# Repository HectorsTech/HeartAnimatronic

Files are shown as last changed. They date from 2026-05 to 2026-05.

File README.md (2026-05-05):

# Realistic Silicone Animatronic Heart

Welcome to the repository for the Realistic Silicone Animatronic Heart project! This project details the construction of a highly realistic, beating animatronic heart.

Compared to simpler designs, this version features a more complex mechanism with three independently moving servos. Controlled by an Arduino Micro and a potentiometer, the heart uses step functions to create a natural-looking motion—gradually filling and then quickly contracting in sequence. The speed of the heartbeat is fully adjustable via the potentiometer.

This is an advanced project that involves intricate mechanical assembly and silicone casting.

## ⚠️ Important Considerations

*   **Complexity:** This project involves tricky assembly, soldering in tight spaces, and intermediate-to-advanced 3D printing and casting techniques.
*   **Hardware Variants:** The code provided is specific to the type of servos used. Please read the assembly instructions carefully to ensure you use the correct Arduino sketch.

## 🛠️ Supplies & Bill of Materials

### Mechanism Components

*   **Microcontroller:** Arduino Micro
*   **Servo Driver:** PCA9685 16-channel servo driver board (or equivalent)
*   **Servos (x3):** DS-843MG servos are *highly recommended* for their strength, which is necessary to stretch the silicone skin. (MG90s servos are supported, but less ideal).
*   **Control:** 10K Potentiometer
*   **Power Input:** 5.5mm DC panel input jack
*   **Power Supply:** 5V DC power supply (must be capable of handling the current draw of 3 high-torque servos)
*   **Hardware:** Various metric screws (M1 to M3)
*   **Wiring:** Jumper cables, slightly thicker wire for the power lines

### Casting Materials

*   **Skin:** 500g Platsil Gel 00 (or equivalent ultra-soft silicone)
*   **Mold:** 2kg Tinsil 7025 (or equivalent mold-making silicone)
*   **Release Agent:** Ease Release 205 (or equivalent)
*   **Coloring:** Silicone pigment in dark red
*   **Mold Box:** A suitable container (can be constructed using hot glue and styrene or similar materials)

### Other Tools & Materials

*   3D Printer and filament (PLA/PETG)
*   Airbrush and acrylic paints (for detailing)
*   Pin vice hand drill
*   Soldering Iron & solder
*   Electrical tape / Heat shrink tubing
*   Fake blood (for final presentation)

## 🖨️ Step 1: 3D Printing

There are no strict material requirements for the prints, only that the structural components be reasonably high-resolution and high-strength.

*   **Layer Height:** ~0.2mm is recommended for most structural parts. The outer shell parts can be printed at a lower resolution.
*   **Supports:** The only parts that typically require supports are the outer shell components.
*   **Base Assembly:** The main base is split into two parts for easier printing. They should be glued together and aligned using two M2 x 10mm screws.

*(Refer to the `.stl` files in the repository for all printable components).*

## ⚙️ Step 2: Assembly Guide

The assembly is compact and can be fiddly. It is highly recommended to reference the project video and images throughout this process.

### 1. Servo Installation

Start by inserting the three servos into the base.
*   **Bottom Pair:** Feed the wires through the slots in the base component (you may need to temporarily remove the plastic connector housing on the end of the wire). Secure the servos with M2 x 10mm screws. If using DS-843MG servos, use the small plastic adaptors to fit the M2 screws into the M3 mounting holes.
*   **Top Servo:** This is a tighter fit. You will need to carefully remove the base plate of the servo (where the wire protrudes) to maneuver it into place. Once seated, screw the base plate back on. The design allows for one screw to secure this top servo, but the friction fit should hold it securely.

### 2. Construct the Arm Linkages

1.  Take a standard servo horn and cut it down so only two holes remain.
2.  Attach two "long link" components to the second hole (furthest from the center) of the horn and screw them in.
3.  Take an opposing pair of "arm" components and screw the "long links" to their flat sides.
4.  **Crucial:** Leave these joints loose enough to move freely without binding.
5.  Create two of these sub-assemblies and attach them to the base using an M3 x 10mm screw for each arm.

### 3. Construct the Top Servo Linkage

1.  Use a two-sided servo horn, cutting it down to leave only two holes per side.
2.  Attach a "short link" on the outermost holes, screwing upwards from the bottom using two M2 x 4mm screws. Leave these joints loose enough to pivot.
3.  Use two more M2 x 4mm screws inserted in the opposite direction through the short links to connect to the "rocker" component later.
4.  Attach the "rocker" component to the top of the base using an M3 x 20mm screw.

### 4. Prepare the Servo Driver Board (PCA9685)

Due to space constraints, you cannot use the standard screw terminal block on the PCA9685.
1.  Solder a positive and negative wire (roughly 40cm long) directly to the power input pads on the driver board.
2.  Mount the board to the base. Use M3 screws on the left side (it will be tight) or M2 screws with nuts. On the right side, use ~12mm M2 screws extending up from the bottom of the base, through the board, and into the "micro standoff" component.
3.  Plug the servos into the appropriate channels on the board (refer to project images for the specific channel layout).

### 5. Assemble the Back-Plate

1.  Mount the potentiometer and the DC power input jack into the holes on the back-plate (use washers if necessary for the potentiometer).
2.  Solder the positive and negative power wires originating from the PCA9685 directly to the terminals of the DC input jack.
3.  Wire the potentiometer: Solder two positive and two negative wires (to share power/ground with the Arduino), and one wire for the signal pin. Using jumper cables with one female end and one stripped end makes connecting to the Arduino and driver board easier.
4.  Attach the back-plate to the main base using three M3 x 20mm screws. *Take care not to pinch any wires.* Ensure the DC input is on the right side, and carefully tuck the top servo wires between the DC input and the servo body.

### 6. Program the Microcontroller

The Arduino Micro generates the heartbeat cycle. The code uses a step function with a sine-wave interval to create a slow expansion and rapid contraction. The speed is modulated by reading the potentiometer.

> [!CAUTION]
> **Code Versions:** Ensure you upload the correct code for your hardware:
> *   `Heart_Beater_Inverted.ino`: Use this if you are using the recommended **DS-843MG** servos.
> *   `Heart_Beater.ino`: Use this if you are using standard **MG90s** servos.

*Recommendation:* Before installing the Arduino into the model, wire everything up on a breadboard to verify the circuit and code logic. It is very difficult to troubleshoot once fully assembled.

### 7. Calibrate and Attach the Servo Horns

This is a delicate but crucial step to ensure the mechanism moves correctly without destroying itself.

1.  Power up the system and ensure the servos are moving based on the code.
2.  Turn the potentiometer to slow the motion down to the absolute minimum speed.
3.  **The Catch:** Unplug the power at the exact moment the servos pause *immediately after* the quick contraction phase.
4.  At this point, the bottom servos are in their "contracted" state. Carefully attach the bottom servo horns so that the arms are pulled close together, almost touching.
5.  The top servo will be in its most counter-clockwise position. Attach its horn so that the "rocker" component is also at its most counter-clockwise limit.
6.  *Note:* You will likely need to test, power off, adjust the horns, and re-test several times to get the alignment perfect.

### 8. Wire the Microcontroller

1.  Attach the insulating plate to the bottom of the Arduino Micro using tiny M1 screws (or electrical tape).
2.  Mount the Arduino to the standoff above the servo driver board using M1 screws. **Note that the Arduino mounts upside down in this design.**
3.  Wire the Arduino to the PCA9685 and the potentiometer according to the circuit diagram.
4.  If using standard jumper wires, you may need to remove the plastic housings from the SDA and SCL pins so they can be bent cleanly out of the way of the moving parts. Insulate them with heat shrink or tape.
5.  Carefully pack all wiring into the space between the Arduino and the servo board.
6.  Power it on and test the potentiometer control!

### 9. Final Structural Assembly

Once the mechanics are tested and working perfectly, attach the outer side panels to the model using M2 x 6mm screws.

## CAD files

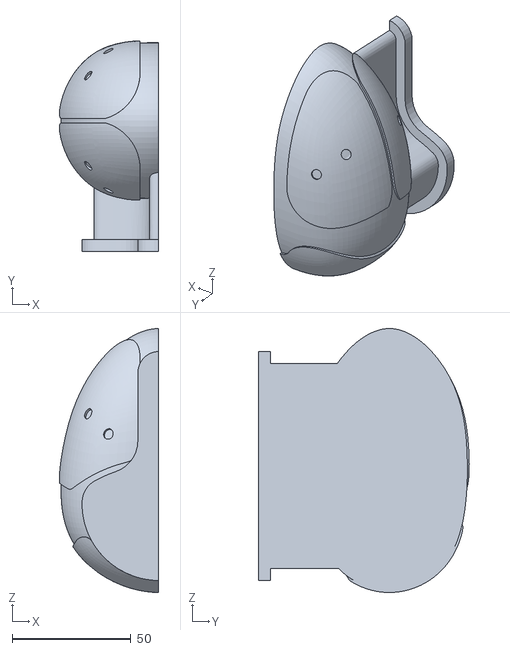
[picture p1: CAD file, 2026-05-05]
Silicone Casting/Form_Left.stl
41.8 x 88.7 x 111.2

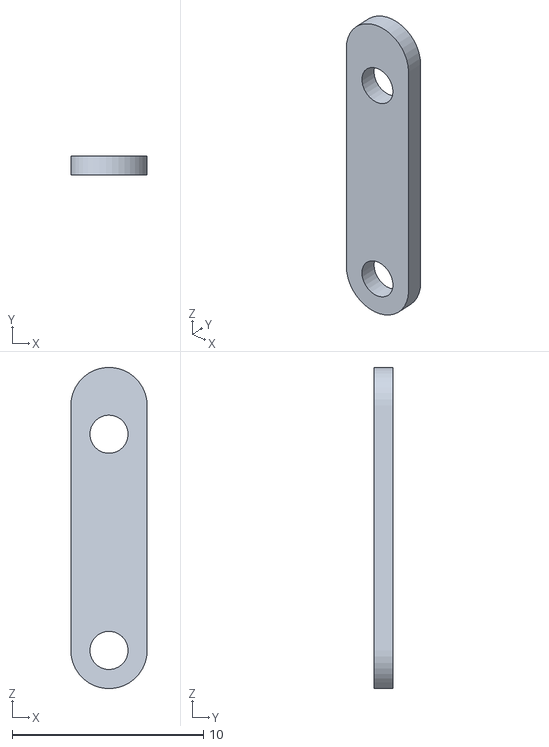
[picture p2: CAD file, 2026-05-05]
STLs/Short_Link_DS-843MG_(x2).stl
4.00 x 1.00 x 16.8

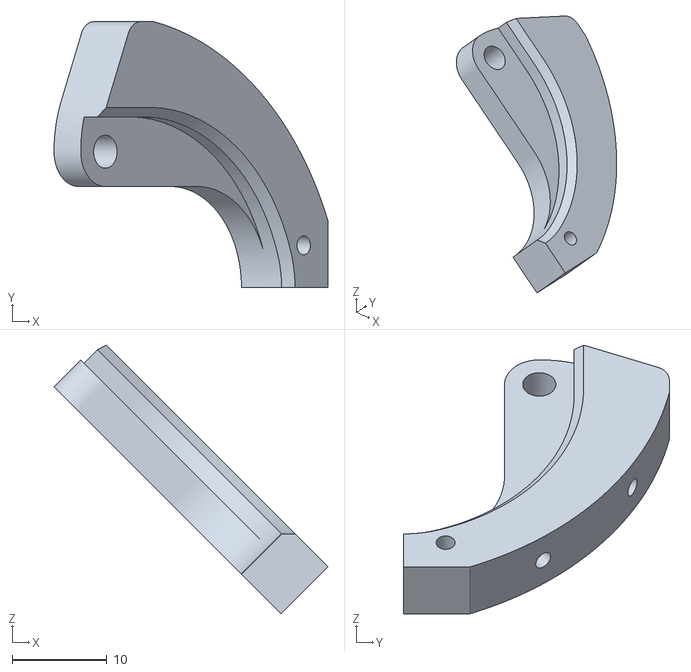
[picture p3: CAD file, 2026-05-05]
STLs/Arm_R_(x2).stl
28.9 x 28.1 x 28.4

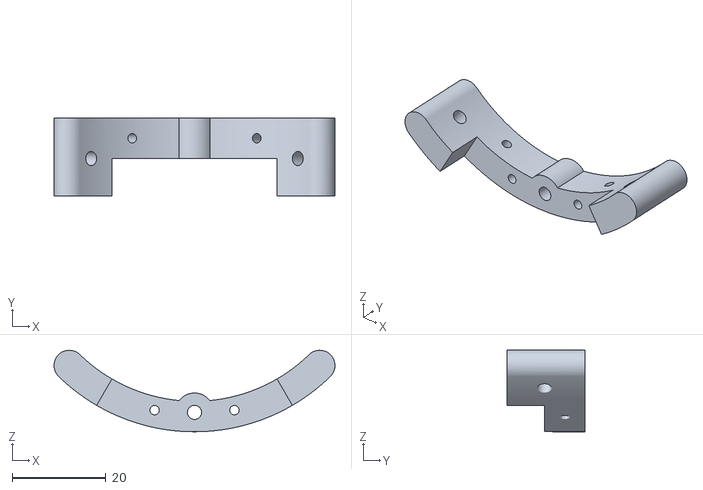
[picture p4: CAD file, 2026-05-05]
STLs/Rocker.stl
59.8 x 16.7 x 17.4

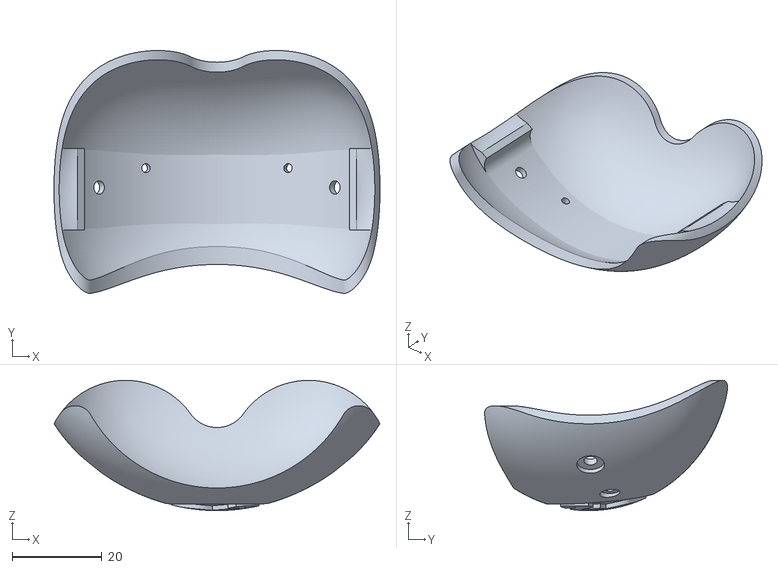
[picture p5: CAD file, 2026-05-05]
STLs/Shell Top.stl
72.8 x 54.2 x 29.1

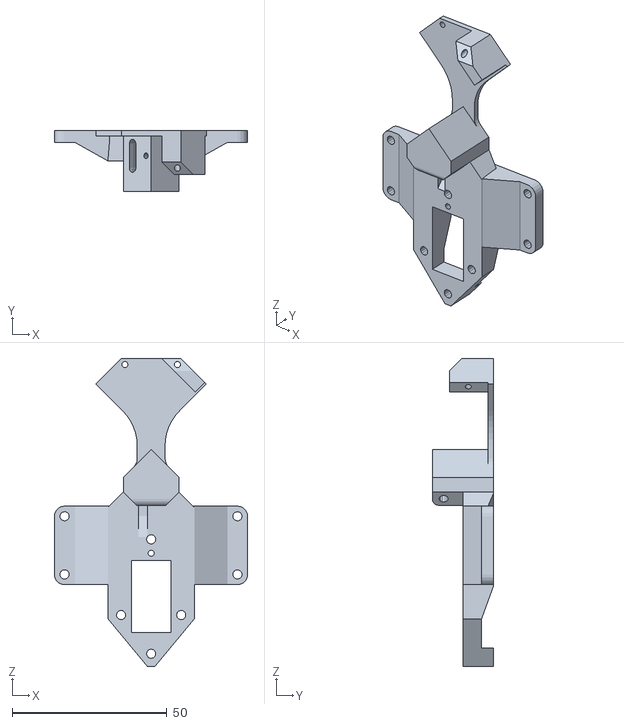
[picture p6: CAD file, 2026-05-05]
STLs/Major_Base.stl
62.5 x 19.8 x 99.6

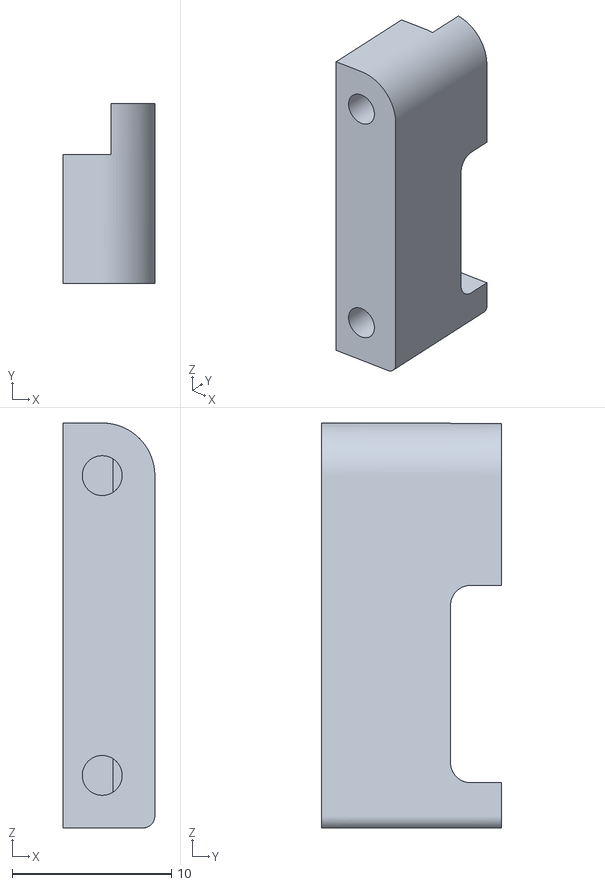
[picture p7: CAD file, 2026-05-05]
STLs/Micro_Standoff.stl
5.75 x 11.3 x 25.4

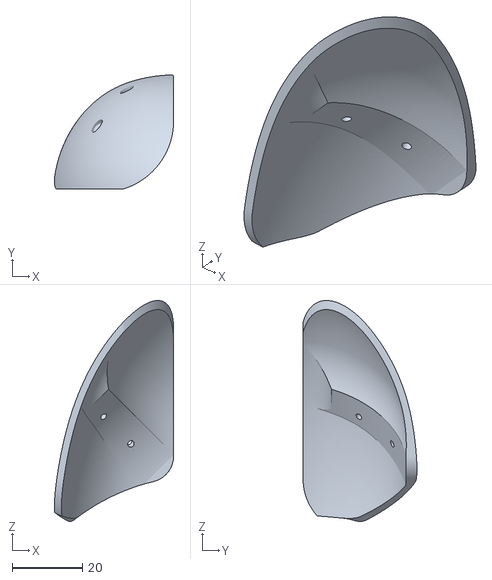
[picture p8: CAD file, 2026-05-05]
STLs/Shell_Lower_Right.stl
34.0 x 32.5 x 63.1

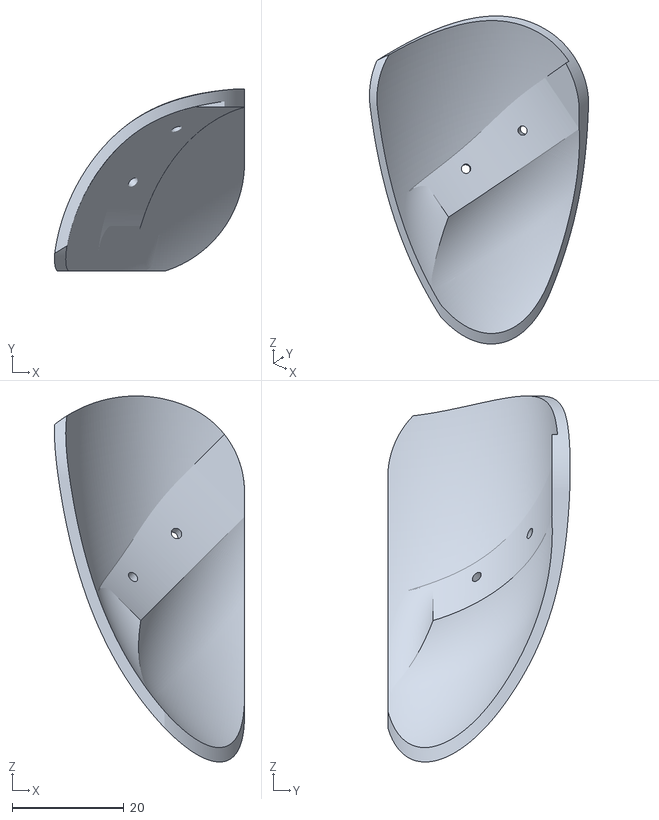
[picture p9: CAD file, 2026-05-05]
STLs/Shell_Upper_Right.stl
34.0 x 32.7 x 65.5

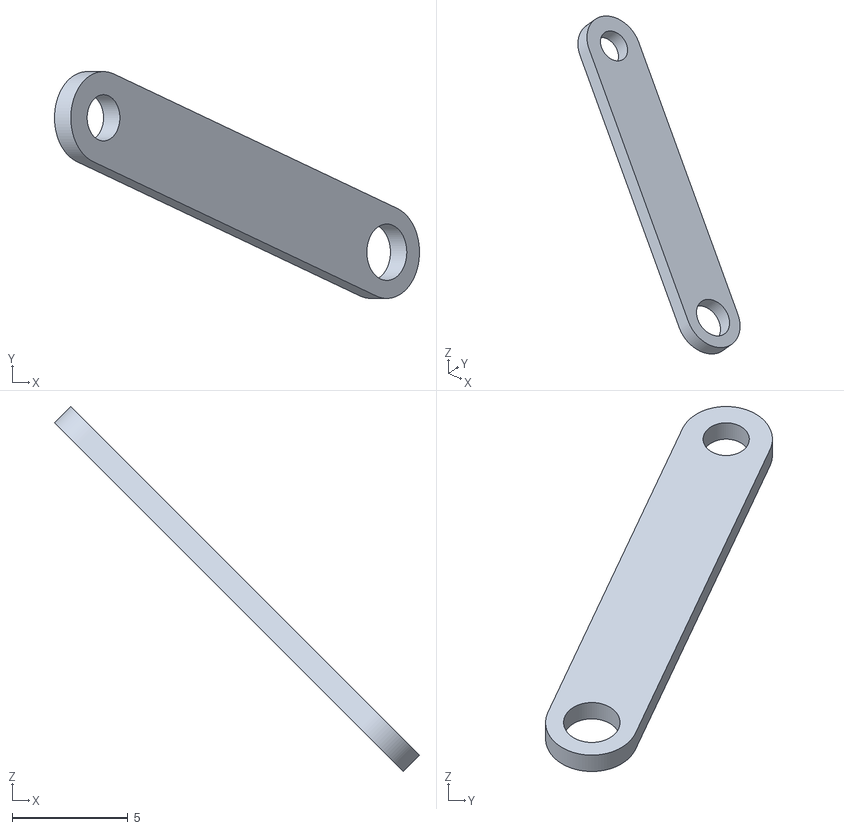
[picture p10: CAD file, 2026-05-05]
STLs/Long_Link_(x4).stl
15.8 x 9.82 x 15.8

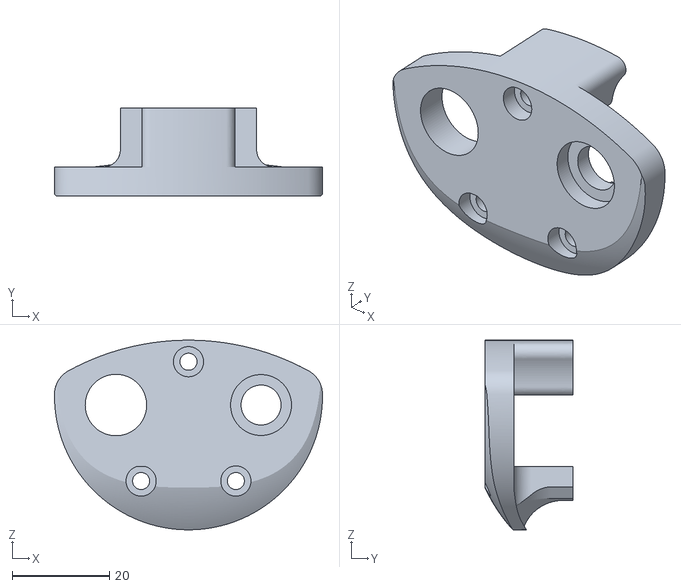
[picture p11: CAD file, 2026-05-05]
STLs/Back Panel.stl
55.0 x 18.1 x 38.9

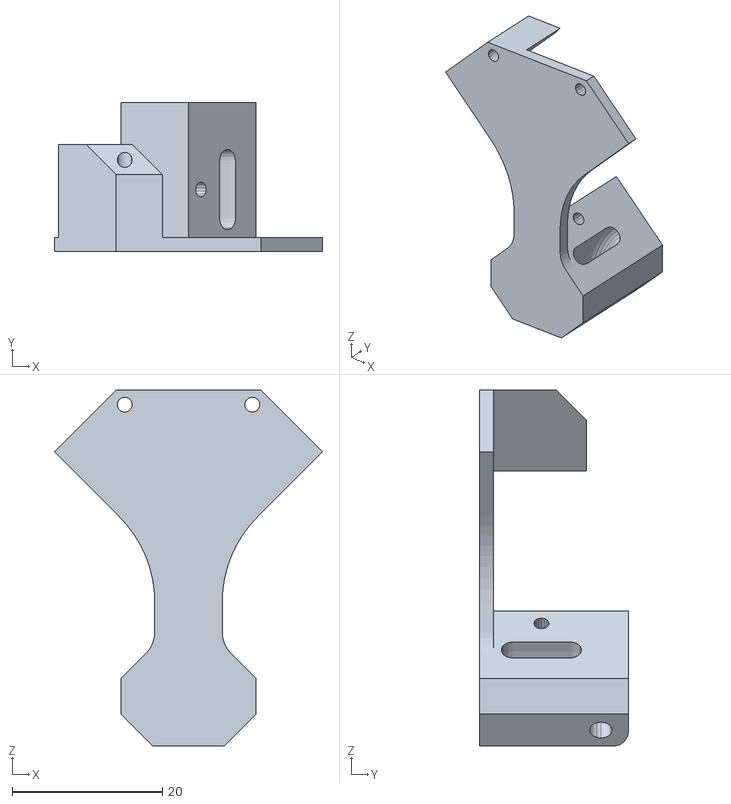
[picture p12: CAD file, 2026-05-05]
STLs/Minor_Base.stl
35.8 x 19.8 x 47.5

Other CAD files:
Silicone Casting/Form_Right.stl
STLs/Arm_L_(x2).stl
STLs/Short_Link_MG90s_(x2).stl
STLs/Shell_Lower_Left.stl
STLs/Shell_Upper_Left.stl

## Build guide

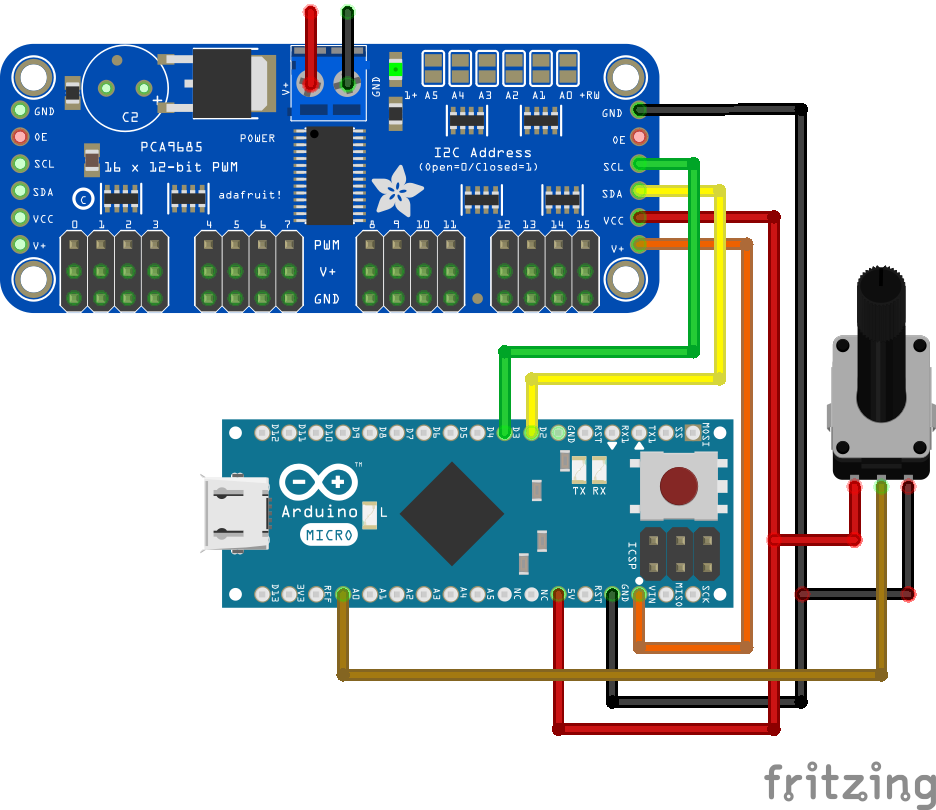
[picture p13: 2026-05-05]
Reference/Wiring_bb.png

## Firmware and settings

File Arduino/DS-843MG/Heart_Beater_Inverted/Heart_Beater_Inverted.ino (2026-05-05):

//Nilheim Mechatronics Servo Heart Mechanism Code
//Make sure you have the Adafruit servo driver library installed >>>>> https://github.com/adafruit/Adafruit-PWM-Servo-Driver-Library
//Potentiometer Pin = A0


#include <Wire.h>
#include <Adafruit_PWMServoDriver.h>

// called this way, it uses the default address 0x40
Adafruit_PWMServoDriver pwm = Adafruit_PWMServoDriver();
// you can also call it with a different address you want
//Adafruit_PWMServoDriver pwm = Adafruit_PWMServoDriver(0x41);
// you can also call it with a different address and I2C interface
//Adafruit_PWMServoDriver pwm = Adafruit_PWMServoDriver(&Wire, 0x40);

// Depending on your servo make, the pulse width min and max may vary, you 
// want these to be as small/large as possible without hitting the hard stop
// for max range. You'll have to tweak them as necessary to match the servos you
// have!
#define SERVOMIN  140 // this is the 'minimum' pulse length count (out of 4096)
#define SERVOMAX  520 // this is the 'maximum' pulse length count (out of 4096)

// our servo # counter
uint8_t servonum = 0;

int sensorValue = 0;        // value read from the pot
int outputValue = 0;

int xval;
int timePeriod = 1000;
float y=0;
float t=0;
float d=330;


void setup() {
  Serial.begin(9600);
  Serial.println("8 channel Servo test!");
  pinMode(A0, INPUT);
  pinMode(2, INPUT);
 
  pwm.begin();
  
  pwm.setPWMFreq(60);  // Analog servos run at ~60 Hz updates

  delay(10);
}

// you can use this function if you'd like to set the pulse length in seconds
// e.g. setServoPulse(0, 0.001) is a ~1 millisecond pulse width. its not precise!
void setServoPulse(uint8_t n, double pulse) {
  double pulselength;
  
  pulselength = 1000000;   // 1,000,000 us per second
  pulselength /= 60;   // 60 Hz
  Serial.print(pulselength); Serial.println(" us per period"); 
  pulselength /= 4096;  // 12 bits of resolution
  Serial.print(pulselength); Serial.println(" us per bit"); 
  pulse *= 1000000;  // convert to us
  pulse /= pulselength;
  Serial.println(pulse);
 // pwm.setPWM(n, 0, pulse);
}

void loop() {
/*pwm.setPWM(0, 0, 330);
pwm.setPWM(1, 0, 330);
pwm.setPWM(2, 0, 380);

delay(50);*/
   
  float i;
  timePeriod = map(analogRead(sensorValue), 0, 1023, 2000, 300);

  for (i=0; i<(3*timePeriod/40); i++) {
    y=sin(i/(timePeriod/20));
    d = 430-(y*100);
    t=350+y*50;
    Serial.print(d);
    Serial.print("   ");
    Serial.print(t);
    pwm.setPWM(0, 0, d);
    pwm.setPWM(1, 0, d);
    pwm.setPWM(2, 0, t);
        Serial.println("  ");
    delay(10);
  }
//  i=0;
  for (i=0; i<(3*timePeriod/400); i++) {
    y=sin(i/(timePeriod/20));
    d=430;
    t=350;
    Serial.print(d);
    Serial.print("   ");
    Serial.print(t);
    pwm.setPWM(0, 0, d);
        pwm.setPWM(2, 0, t);
    Serial.println("  ");
    delay(10);

  }
  for (i=0; i<((7*timePeriod)/400); i++) {
    y=sin(i/(timePeriod/20));
    d=430;
    //t=350+y*50;
    Serial.print(d);
    Serial.print("   ");
    Serial.print(t);
    pwm.setPWM(1, 0, d);
    pwm.setPWM(2, 0, t
    );
                Serial.println("  ");
    delay(10);

  }

}

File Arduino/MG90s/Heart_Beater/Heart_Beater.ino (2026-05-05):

#include <Wire.h>
#include <Adafruit_PWMServoDriver.h>

Adafruit_PWMServoDriver pwm = Adafruit_PWMServoDriver();

// He subido un poco los límites de seguridad por si acaso
#define SERVOMIN  150 
#define SERVOMAX  580 

const int potPin = 34; 

int timePeriod = 1000;
float y = 0;
float t = 0;
float d = 330;

void setup() {
  Serial.begin(115200);
  pinMode(potPin, INPUT);
  
  pwm.begin();
  pwm.setPWMFreq(60); 

  delay(10);
}

void loop() {
  float i;
  
  int valorPot = analogRead(potPin);
  timePeriod = map(valorPot, 0, 4095, 2000, 300);

  // --- Fase de Latido ---
  for (i = 0; i < (3 * timePeriod / 40); i++) {
    y = sin(i / (timePeriod / 20.0));

    // ANTES: d = 430 - (y * 100); -> AHORA: 130 para más recorrido
    d = 430 - (y * 130); 
    
    // ANTES: t = 350 + (y * 50);  -> AHORA: 80 para más recorrido
    t = 350 + (y * 80);
    
    // Seguridad para no pasarnos de los límites del servo
    d = constrain(d, SERVOMIN, SERVOMAX);
    t = constrain(t, SERVOMIN, SERVOMAX);

    pwm.setPWM(0, 0, d);
    pwm.setPWM(1, 0, d);
    pwm.setPWM(2, 0, t);

    Serial.println(d); 
    delay(10);
  }

  // --- Pausas ---
  for (i = 0; i < (10 * timePeriod / 400); i++) {
    d = 430; 
    pwm.setPWM(0, 0, d);
    pwm.setPWM(1, 0, d);
    pwm.setPWM(2, 0, 350);

    Serial.println(d); 
    delay(10);
  }
}
